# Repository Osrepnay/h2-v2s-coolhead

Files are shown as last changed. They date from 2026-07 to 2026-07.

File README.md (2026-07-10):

# Coolhead

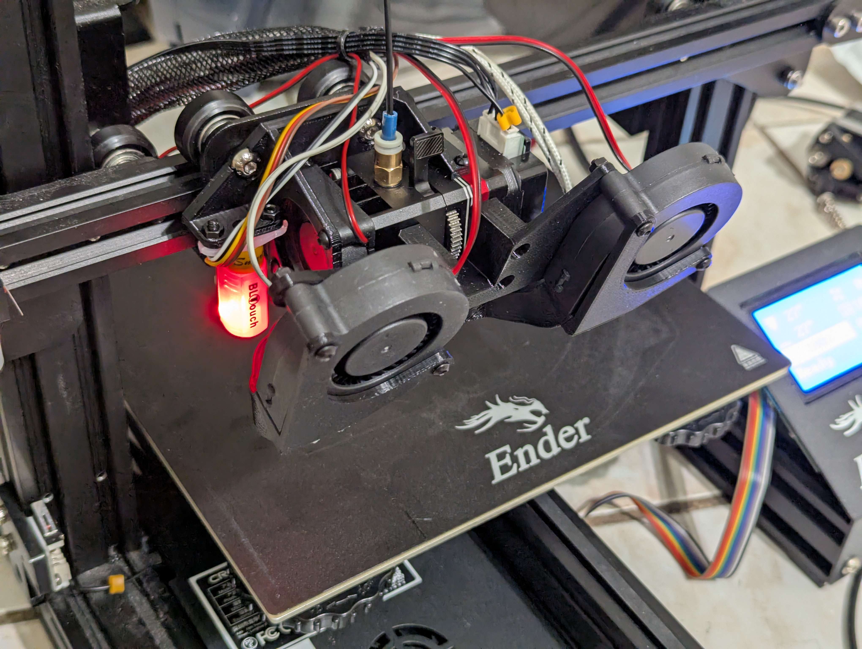
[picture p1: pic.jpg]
picture of the printhead

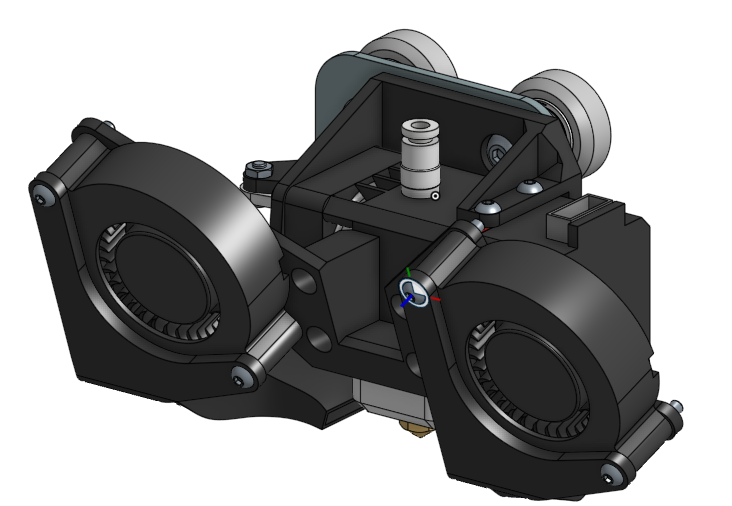
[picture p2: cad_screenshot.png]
cad screenshot


[cad link](https://cad.onshape.com/documents/de9893fea101ddbb259c53bb/w/14a457677c58ecbb5b3d4857/e/d87e13b2c981aecff97c0c8d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)
[stardance link (it's just JOURNAL.md, I started here first and was too lazy to port)](https://stardance.hackclub.com/projects/19029)

I've been meaning to upgrade my Ender 3's printhead,
but then someone gave me a BIQU H2 V2S and BLTouch they weren't using,
so then I had to upgrade my printhead.

This mod replaces the stock extruder with the BIQU H2 V2S
and adds replaces the stock part cooling with two 5015 fans (I used the GDSTime models).

I wanted silicone wiring, so there's some custom wiring in my build.
You will need a crimper and wire strippers to make it.
Make sure your crimper is not too wide (I didn't).

Wiring diagram:
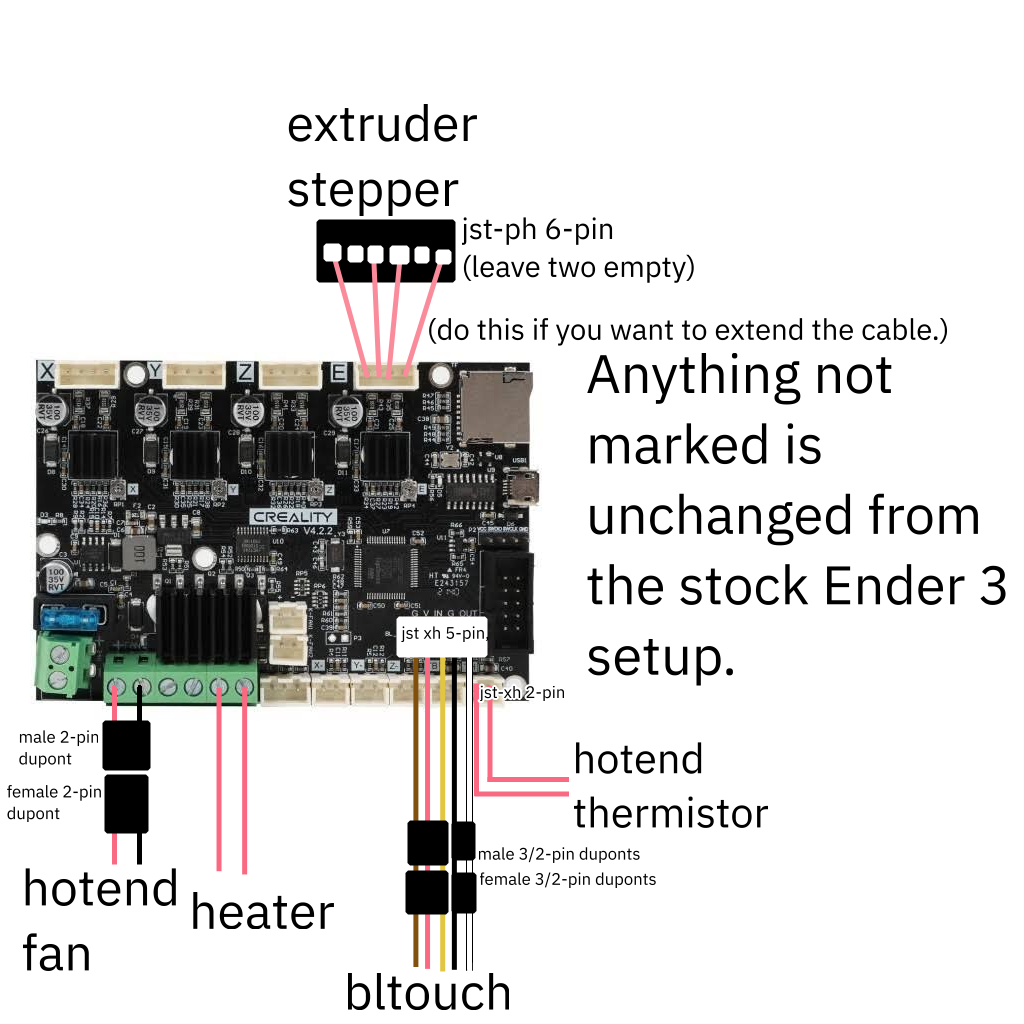
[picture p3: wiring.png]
wiring diagram


Here's a timelapse of this printhead printing the [pin-support challenge from fullcontrol.xyz](https://fullcontrol.xyz/#/models/67cf20) (click the image to open):
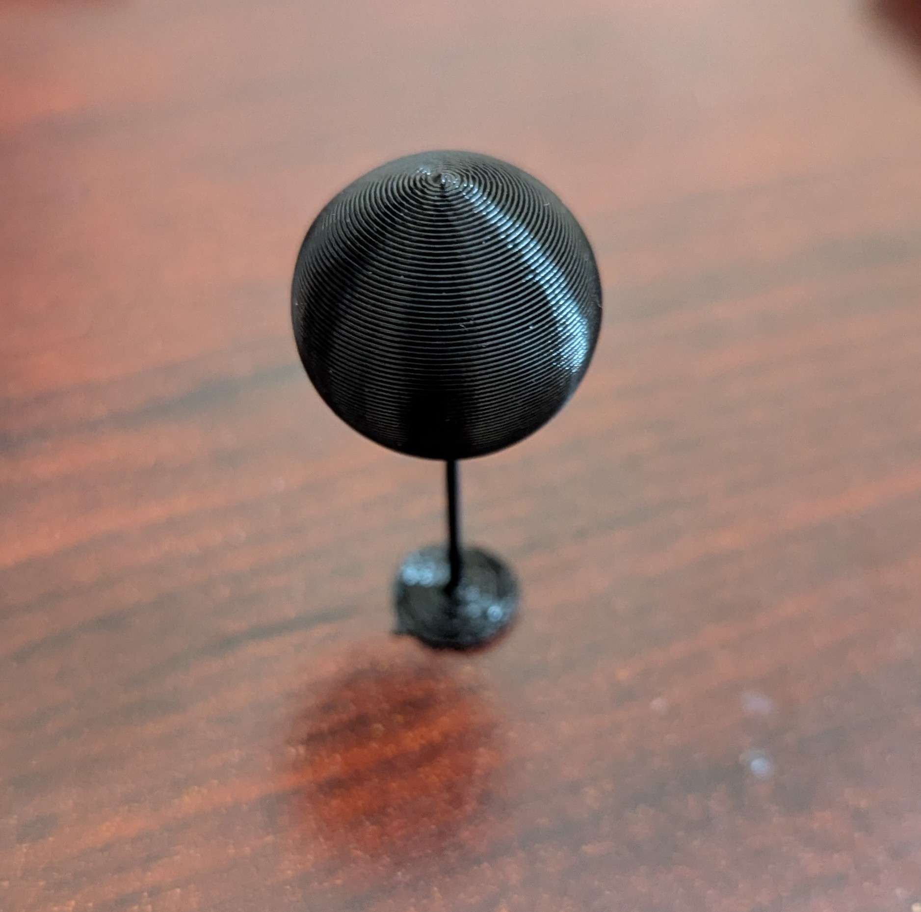
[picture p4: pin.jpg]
(https://user-cdn.hackclub-assets.com/019f49bf-6412-732e-ad26-443bd25fdffd/out.mp4)


<br>
<br>
<br>
<br>
<br>
<br>

how i feel when onshape doesn't have 3d sketches
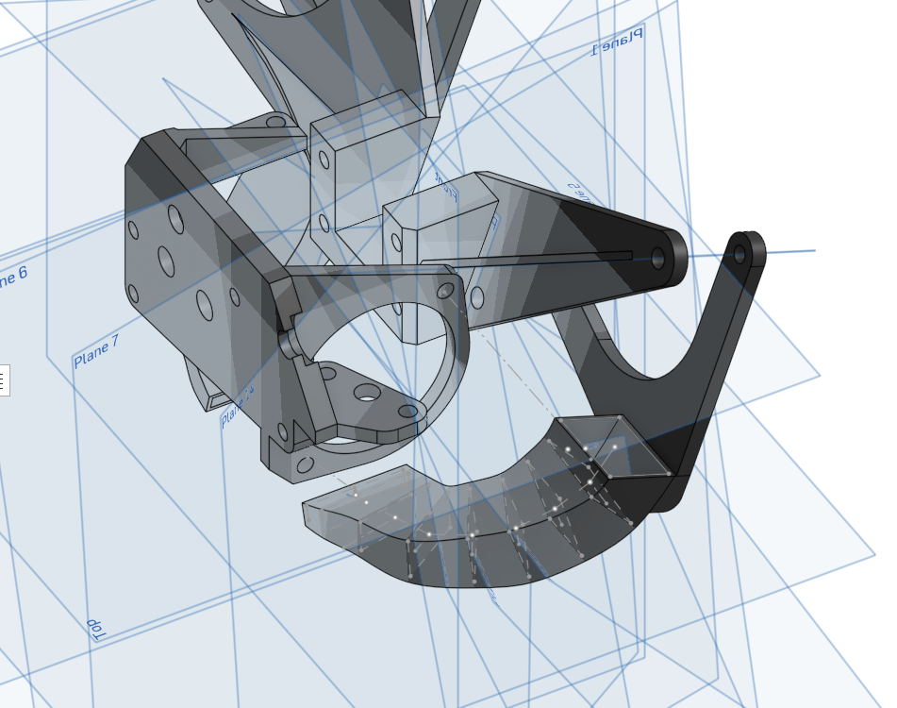
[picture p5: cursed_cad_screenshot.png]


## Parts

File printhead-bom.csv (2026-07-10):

Item Name | Qty | Price (total) (USD) | Item link | Notes
BIQU H2 V2S | 1 | $79.69 | https://biqu.equipment/products/biqu-h2-v2s-extruder-for-b1-bx-ender-3-3-v2-5-6-cr6-10 | US warehouse price, obtained for free
BLTouch | 1 | $29.98 | https://3dprinteruniverse.com/products/antclabs-bltouch-auto-bed-leveling-sensor | I got one for free, original but BLTouch prices are all over the place. You could probably get a clone and be fine if the mounting is the same.
GDSTime 5015 fans | 2 | $19.99 | https://www.amazon.com/dp/B0DN6DT2S8
22awg wire | 1 | $7.88 | https://www.amazon.com/dp/B08F7BMVJW
JST-XH splitter | 1 | $4.99 | https://www.amazon.com/dp/B0GV41FVN3
JST-PH crimp sockets | 6 | $0.04 | https://www.digikey.ca/en/products/detail/jst-sales-america-inc/SPH-001T-P0-5L/27687540 | Minimum order quantity of 100 on DigiKey
JST-XH extension | 2 | $1.88 | https://www.digikey.ca/en/products/detail/adafruit-industries-llc/5497/16680577
JST-PH 6-pin housing | 1 | $0.16 | https://www.digikey.ca/en/products/detail/jst-sales-america-inc/PHR-6/608604
JST-XH 4-pin housing | 1 | $0.16 | https://www.digikey.ca/en/products/detail/jst-sales-america-inc/XHP-4/683353
JST-XH crimp socket | 4 | $0.15 | https://www.digikey.ca/en/products/detail/jst-sales-america-inc/BXH-001T-P0-6/7423881
offbrand JST-XH 5-pin housing | 1 | $0.16 | https://www.digikey.ca/en/products/detail/adam-tech/25CH-B-05/9830464 | Official was out of stock :(
Mini-PV (Dupont) pin | 7 | $0.33 | https://www.digikey.ca/en/products/detail/amphenol-cs-fci/75653-005LF/1487453
Mini-PV (Dupont) 2-pin housing | 2 | $1.28 | https://www.digikey.ca/en/products/detail/amphenol-cs-fci/65039-035LF/1002656
Mini-PV (Dupont) 3-pin housing | 1 | $0.42 | https://www.digikey.ca/en/products/detail/amphenol-cs-fci/65039-034ELF/4272533
Assorted M3 hardware | 1 | $7.84 | https://www.amazon.com/dp/B0FQJQNHF5
Total Price (USD): | $180.73
you'll also need a crimper+wire strippers unless you go premade-cables route, which is probably cheaper if you don't have one already

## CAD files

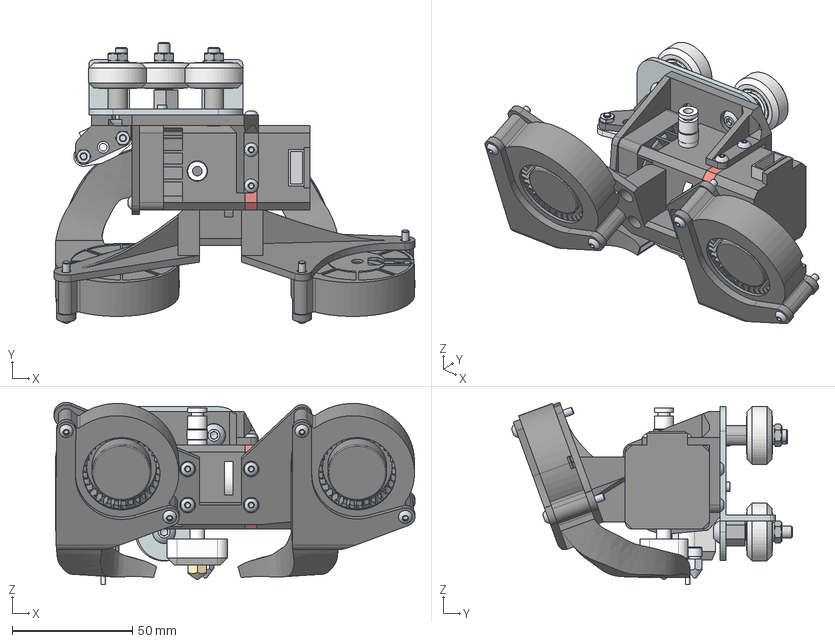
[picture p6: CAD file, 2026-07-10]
printhead.step
150.1 x 116.7 x 75.8 mm
M5 Self-locking nut x 3
Socket button head screw M3x0.5 x 8 x 8
Hex thin nut grade A & B M3 x 2
Socket button head screw M3x0.5 x 25 x 4
E plate(???)
Spacers for rollers x 2
turbine x 2
Socket button head screw M3x0.5 x 6 x 4
Eccentric column
Socket button head screw M5x0.8 x 30 x 3
fan housing x 2
left duct
bltouch housing
bltouch pin
right duct
Socket button head screw M3x0.5 x 16 x 2
Hotend x 9
extruder gear
nozzle
fan mounts
backplate
Rollers x 3
M5 washer1 x 3
625pillow x 24

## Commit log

2026-07-10 add wiring to readme
2026-07-10 fix wiring and bom
    [printhead-bom.csv]
2026-07-10 cad link
